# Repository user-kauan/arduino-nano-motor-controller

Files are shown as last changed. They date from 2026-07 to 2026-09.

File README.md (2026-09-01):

# 🔧 Arduino Nano Motor Controller

> Placa de circuito impresso baseada em Arduino Nano para controle PWM de motores DC, com telemetria de corrente, tensão, temperatura e rotação, e proteção térmica automática.

---

## 📌 Sobre o projeto

A placa controla a velocidade de um motor DC via PWM, monitora suas condições de operação em tempo real (corrente, tensão, temperatura e rotação) e interrompe automaticamente o motor em caso de superaquecimento ou sobrecorrente.

## 🖼️ Visão geral

<p align="center">
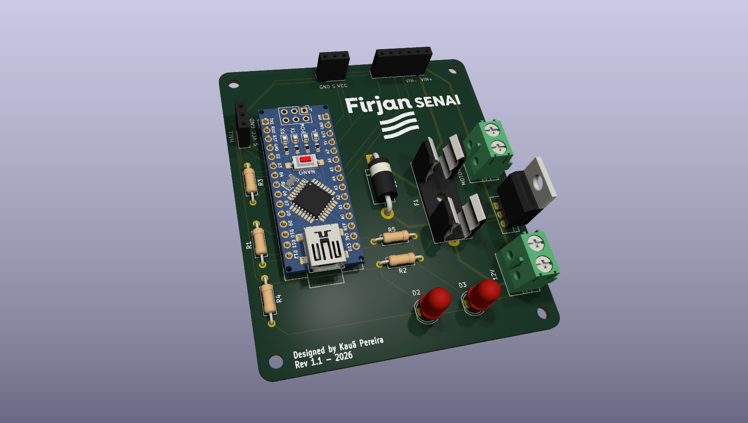
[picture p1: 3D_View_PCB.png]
Visão 3D da PCB
  
</p>
<p align="center">
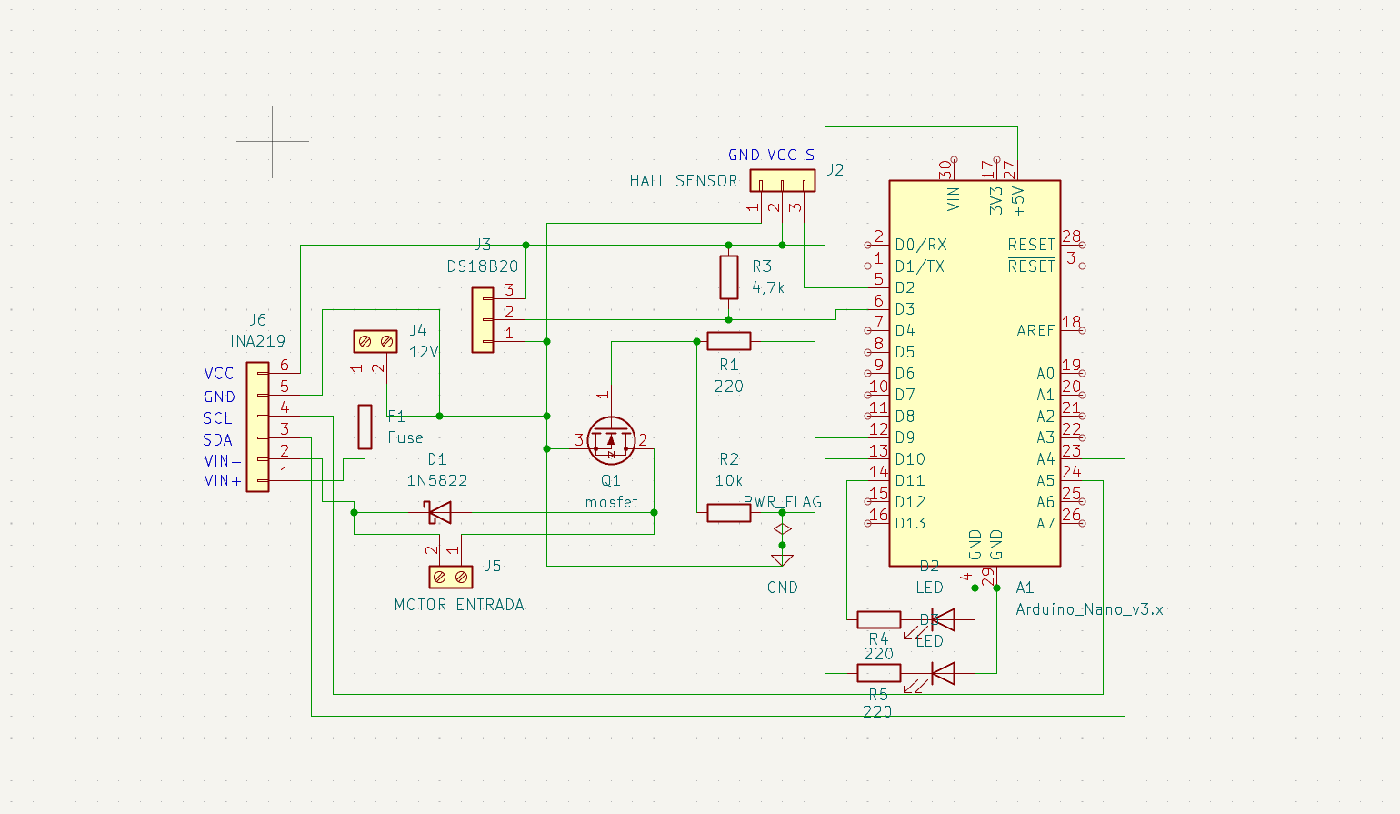
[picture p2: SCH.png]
Esquemático do circuito
  
</p>

## ⚙️ Funcionalidades

- **Controle de velocidade via PWM**, ajustável remotamente por comando serial
- **Monitoramento de temperatura em tempo real** com sensor DS18B20
- **Telemetria elétrica** via módulo INA219 (corrente, tensão e potência em tempo real por I2C)
- **Medição de RPM** via sensor Hall, usando interrupção externa para não perder pulsos em alta rotação
- **Trava de segurança automática**: desliga o motor em caso de superaquecimento, sobrecorrente, ou falha/desconexão do sensor de temperatura
- **Indicação visual de status** via LEDs (rodando / parado / falha)
- **Log contínuo via Serial** com todos os dados de operação

## 🧰 Especificações e limites da placa

| Especificação | Valor |
|---|---|
| Tensão máxima | 12V DC |
| Corrente máxima do motor | Até 3A em **STALL** (rotor travado) — o motor recomendado para uso contínuo deve consumir **0.5A - 1A** em operação normal, não 3A constantes |
| Fusível recomendado | 5x20mm, **2A**, tipo slow-blow (retardado) |
| Proteções | Soquete para fusível cilíndrico 5x20mm + diodo de proteção 1N5822 |
| Acionamento do motor | MOSFET IRLZ44N |

## 📋 Lista de materiais (BOM)

### Placa principal e circuito

| Qtd | Componente | Descrição |
|---|---|---|
| 1 | Arduino Nano V3 | Microcontrolador principal |
| 1 | MOSFET IRLZ44N | Controle PWM do motor |
| 1 | Diodo 1N5822 | Proteção flyback / roda livre |
| 2 | Borne terminal 5mm (2 pinos) | Entrada de alimentação 12V e saída para o motor |
| 1 | Soquete de fusível | Porta-fusível 5x20mm |
| 2 | LED 5mm | Indicação de status / sinalização |
| 1 | Resistor 4.7kΩ | Pull-up do sensor de temperatura |
| 1 | Resistor 10kΩ | Pull-down do MOSFET |
| 2 | Resistor 220Ω | Limitação de corrente dos LEDs |
| 2 | Header fêmea 1x03 | Sensor Hall e DS18B20 |
| 1 | Header fêmea 1x06 | Conector do módulo INA219 |
| 2 | Header fêmea 1x15 | Soquete para encaixe do Arduino Nano (um de cada lado) |

### Sensores externos suportados

| Sensor | Função | Comunicação |
|---|---|---|
| DS18B20 | Temperatura | 1-Wire
| INA219 | Corrente, tensão e potência | I2C |
| Sensor Hall (3 pinos) | Rotação / RPM | Digital |

## 🔌 Montagem

O Arduino Nano é encaixado diretamente nos headers da própria PCB — não há fiação manual entre o microcontrolador e os componentes da placa, já que o layout do circuito fixa essas conexões fisicamente. Basta encaixar o Nano na posição correta (a serigrafia indica a orientação) e conectar os sensores externos (DS18B20, INA219, sensor Hall) nos headers dedicados.

> 💡 **Sobre a soldagem:** é possível soldar todos os componentes diretamente na placa, incluindo o próprio Arduino Nano direto nos pinos da PCB, sem usar headers. **A recomendação, porém, é usar headers fêmea** (os 1x15 para o Nano e os menores para os sensores). Isso permite remover o Arduino ou os sensores para testes, reprogramação fora da placa, ou substituição em caso de defeito, sem precisar dessoldar nada.

**Mapeamento fixo definido pela placa:**

| Função | Pino do Nano |
|---|---|
| PWM do motor (gate do MOSFET) | D9 |
| DS18B20 (temperatura) | D3 |
| Sensor Hall (RPM) | D2 |
| INA219 (I2C) | A4 (SDA) / A5 (SCL) |
| LED — motor rodando | D11 |
| LED — motor parado / falha | D10 |

## 🖥️ Firmware

O código-fonte está em [`motor_code.ino`](./motor_code.ino).

### Bibliotecas necessárias
Instale pelo Gerenciador de Bibliotecas da Arduino IDE:
- `OneWire`
- `DallasTemperature`
- `Adafruit INA219` (+ `Adafruit BusIO`)

### Comandos via Serial (9600 baud)

| Comando | Ação |
|---|---|
| `Vxxx` | Define a velocidade do motor (0–255). Ex: `V150` |
| `S` | Para o motor |
| `R` | Reseta uma falha de segurança (temperatura, corrente ou sensor desconectado) |

### Lógica de segurança
- Se a temperatura ultrapassar **70°C**, o motor é desligado automaticamente
- Se a corrente ultrapassar **3A**, o motor é desligado automaticamente
- Se o sensor DS18B20 desconectar ou falhar, o motor também é desligado (falha "às cegas" não é permitida)
- Uma vez em falha, o motor **permanece desligado** até o comando `R` ser enviado — evita religamento automático indesejado

### Como gravar
1. Abra `motor_code.ino` na Arduino IDE
2. Selecione a placa **Arduino Nano** e a porta serial correta
3. Instale as bibliotecas listadas acima
4. Grave e abra o Monitor Serial (9600 baud) para acompanhar os dados em tempo real

## 🖥️ Hardware — como fabricar

1. Baixe os arquivos de fabricação em [`Gerbers_Files.zip`](./Gerbers_Files.zip) e mande fabricar a placa (usado PCBWay no projeto original)
2. Solde os componentes conforme a lista de materiais acima
3. Conecte os sensores externos nos headers correspondentes
4. Conecte a alimentação de 12V e o motor DC nos bornes terminais

### Abrindo o projeto no KiCad
```
PCB_Motor.kicad_pro   → projeto principal (abra este primeiro)
PCB_Motor.kicad_sch   → esquemático
PCB_Motor.kicad_pcb   → layout da placa
```

## 📂 Estrutura do repositório

```
├── 3D_View_PCB.png            → render 3D da placa
├── SCH.png                     → imagem do esquemático
├── Gerbers_Files.zip           → arquivos para fabricação
├── PCB_Motor.kicad_pcb         → layout da placa (KiCad)
├── PCB_Motor.kicad_pro         → projeto KiCad
├── PCB_Motor.kicad_sch         → esquemático (KiCad)
├── motor_code.ino              → código-fonte do Arduino
├── LICENSE                     → MIT
└── README.md
```

## 📄 Licença

Este projeto está sob a licença MIT — veja o arquivo [LICENSE](./LICENSE) para mais detalhes.

---

#Engenharia #Eletronica #Hardware #PCBDesign #KiCad #Arduino #FirjanSENAI #SistemasEmbarcados #GitHub #OpenSource #Automação

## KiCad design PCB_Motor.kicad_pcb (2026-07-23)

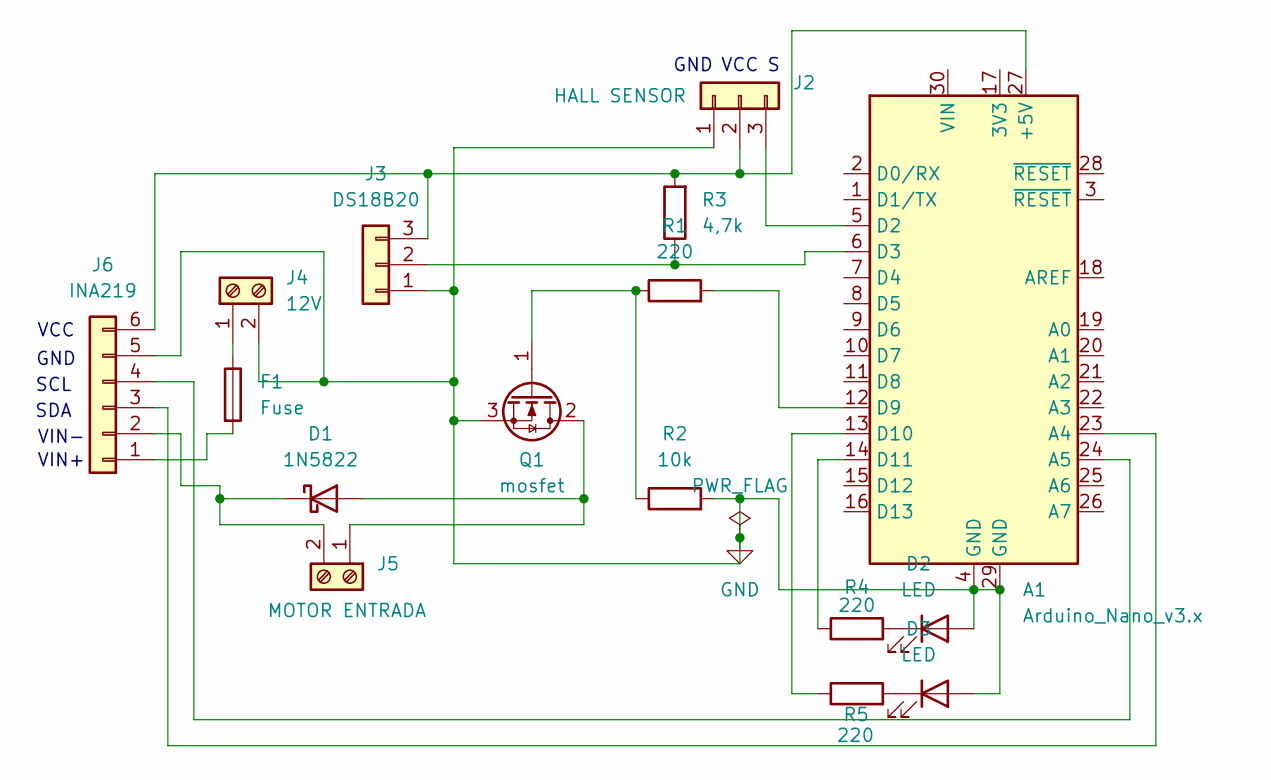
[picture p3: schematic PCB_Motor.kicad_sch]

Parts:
A1: Arduino_Nano_v3.x; Arduino_Nano
D1: 1N5822; D_DO-201AD_P15.24mm_Horizontal
D2, D3: LED; LED_D5.0mm
F1: Fuse; Fuseholder_Cylinder-5x20mm_Schurter_0031_8201_Horizontal_Op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
J2: HALL SENSOR; PinSocket_1x03_P2.54mm_Vertical
J3: DS18B20; PinSocket_1x03_P2.54mm_Vertical
J4: 12V; TerminalBlock_MaiXu_MX126-5.0-02P_1x02_P5.00mm
J5: MOTOR ENTRADA; TerminalBlock_MaiXu_MX126-5.0-02P_1x02_P5.00mm
J6: INA219; PinSocket_1x06_P2.54mm_Vertical
Q1: mosfet; TO-220-3_Vertical
R1, R4, R5: 220; R_Axial_DIN0207_L6.3mm_D2.5mm_P10.16mm_Horizontal
R2: 10k; R_Axial_DIN0207_L6.3mm_D2.5mm_P10.16mm_Horizontal
R3: 4,7k; R_Axial_DIN0207_L6.3mm_D2.5mm_P10.16mm_Horizontal

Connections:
GND: A1.4 (GND), A1.29 (GND), D2.2 (A), D3.2 (A), J2.1, J3.1, J4.2, J6.5, Q1.3 (S), R2.2
unnamed: A1.27 (+5V), J2.2, J3.3, J6.6, R3.2
unnamed: A1.23 (A4), J6.3
unnamed: A1.24 (A5), J6.4
unnamed: A1.5 (D2), J2.3
unnamed: A1.6 (D3), J3.2, R3.1
unnamed: A1.12 (D9), R1.2
unnamed: A1.13 (D10), R5.1
unnamed: A1.14 (D11), R4.1
unnamed: D1.2 (A), J5.1, Q1.2 (D)
unnamed: D1.1 (K), J5.2, J6.2
unnamed: D2.1 (K), R4.2
unnamed: D3.1 (K), R5.2
unnamed: F1.1, J4.1
unnamed: F1.2, J6.1
unnamed: Q1.1 (G), R1.1, R2.1

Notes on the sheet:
GND
GND
VIN+
SDA
SCL
VCC
VCC
VIN-

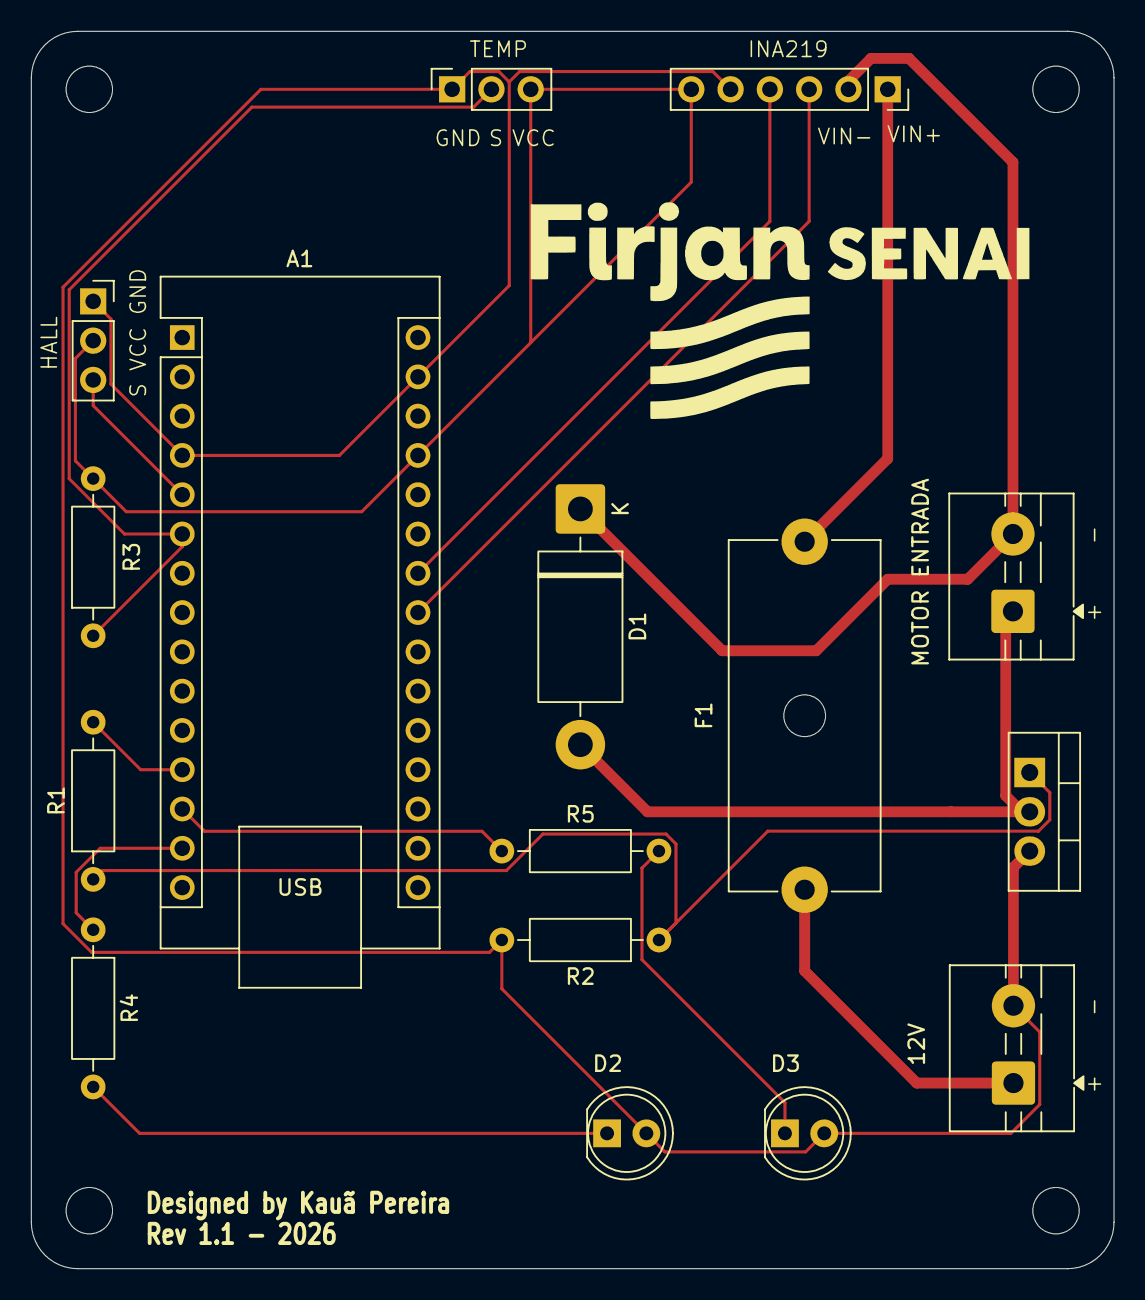
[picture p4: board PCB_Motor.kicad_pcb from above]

Board: 2 copper layers, 70.0 x 80.0 mm, 16 parts (0 on the bottom side), 16 nets.

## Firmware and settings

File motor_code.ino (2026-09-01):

/*
  Indicadores:
   - LED D11 -> acende quando o motor esta RODANDO
   - LED D10 -> acende quando o motor esta PARADO
                (pisca rapido se parado por falha de seguranca)

  Bibliotecas necessárias (Gerenciador de Bibliotecas):
   - OneWire
   - DallasTemperature
   - Adafruit INA219 (+ Adafruit BusIO)

  Comandos via Serial (9600 baud):
   - Vxxx  -> define velocidade (0-255), ex: V150
   - S     -> para o motor
   - R     -> reseta uma falha de seguranca (temperatura ou corrente)
*/

#include <Wire.h>
#include <OneWire.h>
#include <DallasTemperature.h>
#include <Adafruit_INA219.h>

// ---------- Pinos ----------
#define PIN_ONEWIRE   3   // DS18B20
#define PIN_MOTOR     9   // Gate do MOSFET (PWM)
#define PIN_LED_RUN   11  // LED - motor rodando
#define PIN_LED_STOP  10  // LED - motor parado

// ---------- Parâmetros de segurança ----------
const float TEMP_MAX = 70.0;        // °C - desliga motor acima disso
const float CORRENTE_MAX_A = 3.0;   // A  - desliga motor acima disso (ajuste conforme o motor/fusivel novos)
const unsigned long INTERVALO_LEITURA = 1000; // ms

// ---------- Objetos ----------
OneWire oneWire(PIN_ONEWIRE);
DallasTemperature sensores(&oneWire);
Adafruit_INA219 ina219;

unsigned long ultimaLeitura = 0;

// ---------- Controle do motor ----------
int velocidadeMotor = 0;     // 0-255 (duty cycle do PWM)
bool motorHabilitado = true; // false quando trava por segurança
bool ina219OK = false;       // true se o INA219 foi encontrado no setup

// ---------- Piscada do LED de falha ----------
unsigned long ultimoPiscar = 0;
bool estadoPiscaLed = false;

void setup() {
  Serial.begin(9600);

  pinMode(PIN_MOTOR, OUTPUT);
  pinMode(PIN_LED_RUN, OUTPUT);
  pinMode(PIN_LED_STOP, OUTPUT);

  analogWrite(PIN_MOTOR, 0); // motor desligado no início

  Wire.begin();
  sensores.begin();

  ina219OK = ina219.begin();
  if (!ina219OK) {
    Serial.println(F("Falha ao encontrar o INA219! Seguindo sem leitura de corrente/tensao."));
  }

  Serial.println(F("Sistema iniciado."));
  Serial.println(F("Comandos: Vxxx (velocidade 0-255) | S (parar) | R (reset de falha)"));
}

void loop() {
  lerComandoSerial();

  unsigned long agora = millis();
  if (agora - ultimaLeitura >= INTERVALO_LEITURA) {
    ultimaLeitura = agora;

    // --- Temperatura (DS18B20) ---
    sensores.requestTemperatures();
    float temperatura = sensores.getTempCByIndex(0);

    // --- Corrente / Tensão (INA219, só se detectado) ---
    float tensao = 0;
    float corrente_mA = 0;
    float potencia_mW = 0;
    if (ina219OK) {
      tensao = ina219.getBusVoltage_V();
      corrente_mA = ina219.getCurrent_mA();
      potencia_mW = ina219.getPower_mW();
    }

    // --- Lógica de segurança ---
    bool faltaCorrente = ina219OK && ((corrente_mA / 1000.0) > CORRENTE_MAX_A);
    if (temperatura > TEMP_MAX || faltaCorrente) {
      motorHabilitado = false;
      Serial.println(F("!! FALHA: motor desligado por seguranca !!"));
    }

    // --- Log ---
    Serial.print(F("Temp: ")); Serial.print(temperatura); Serial.print(F(" C"));
    if (ina219OK) {
      Serial.print(F(" | Tensao: ")); Serial.print(tensao); Serial.print(F(" V"));
      Serial.print(F(" | Corrente: ")); Serial.print(corrente_mA); Serial.print(F(" mA"));
      Serial.print(F(" | Potencia: ")); Serial.print(potencia_mW); Serial.print(F(" mW"));
    } else {
      Serial.print(F(" | INA219 nao detectado"));
    }
    Serial.print(F(" | PWM Motor: ")); Serial.println(velocidadeMotor);
  }

  bool motorRodando = motorHabilitado && velocidadeMotor > 0;
  bool emFalha = !motorHabilitado;

  // --- LED de motor rodando ---
  digitalWrite(PIN_LED_RUN, motorRodando ? HIGH : LOW);

  // --- LED de motor parado (pisca rapido se for falha de segurança) ---
  if (!motorRodando) {
    if (emFalha) {
      // pisca rapido (a cada 150ms) para indicar falha
      if (millis() - ultimoPiscar >= 150) {
        ultimoPiscar = millis();
        estadoPiscaLed = !estadoPiscaLed;
        digitalWrite(PIN_LED_STOP, estadoPiscaLed ? HIGH : LOW);
      }
    } else {
      digitalWrite(PIN_LED_STOP, HIGH); // parado normal - aceso fixo
    }
  } else {
    digitalWrite(PIN_LED_STOP, LOW);
  }

  // --- Aplica PWM no motor (via gate do MOSFET) ---
  analogWrite(PIN_MOTOR, motorHabilitado ? velocidadeMotor : 0);
}

void lerComandoSerial() {
  if (Serial.available() > 0) {
    char c = Serial.read();
    if (c == 'V' || c == 'v') {
      int v = Serial.parseInt();
      v = constrain(v, 0, 255);
      velocidadeMotor = v;
      Serial.print(F("Nova velocidade: ")); Serial.println(velocidadeMotor);
    } else if (c == 'R' || c == 'r') {
      motorHabilitado = true;
      Serial.println(F("Motor reabilitado (reset de falha)."));
    } else if (c == 'S' || c == 's') {
      velocidadeMotor = 0;
      Serial.println(F("Motor parado."));
    }
  }
}
